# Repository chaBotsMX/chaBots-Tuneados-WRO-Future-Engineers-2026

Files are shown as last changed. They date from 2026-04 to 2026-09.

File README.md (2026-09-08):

# ChaBots - WRO Future Engineers 2026

<!--<img src="https://github.com/chaBotsMX/chaBots-NERV-WRO-Future-Engineers-2025/blob/docs-nacional/v-photos/resources/ChaBotsLogo.png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" width="250">-->

## Follow us!

<!-- Facebook -->

<a  href="https://www.facebook.com/chabotsMX/">

Facebook

</a>

<!-- Instagram -->

<a  href="https://www.instagram.com/chabotsmx/"  target="_blank">

Instagram

</a>

<!-- YouTube -->

<a  href="https://www.youtube.com/@chabotsmx1956/videos"  target="_blank">

YouTube

</a>

This repository contains the documentation for **ChaBots'** participation in the **WRO Future Engineers 2026** category. Our robot was designed and built by a team of Mexican students passionate about robotics and education.

## Competition Videos 

Watch Pistonudo complete the Open and Obstacles challenges. Select a preview to open the corresponding video on YouTube.

| Open Challenge | Obstacles Challenge |
|:---:|:---:|
| Watch the Open Challenge (https://youtu.be/oslJ-CmbmxM) | Watch the Obstacles Challenge (https://youtu.be/23dmH0szIEk) |
| [▶ Watch Open Challenge](https://youtu.be/oslJ-CmbmxM) | [▶ Watch Obstacles Challenge](https://youtu.be/23dmH0szIEk) |

## 📜 Table of Contents

🎬 [Competition Videos](#competition-videos)

1. 🧑‍💻 [The Team](#the-team)
2. 🎯 [The Challenge](#the-challenge)
3. 🏆 [Lessons from the Previous Season](#experience-from-last-year)
4. 🔬 [Research, Development and Decision Log](#rd)
5. 🤖 [Final Robot Architecture](#robot-overview)
6. ⚙️ [Mobility Management](#mobility-management)
7. 💡 [Power, Electronics and Sensor Management](#electronics)
8. 💻 [Software Architecture and Control](#software-architecture)
9. 🚧 [Obstacle Management](#obstacle-management)
10. 🧪 [Testing, Validation and Results](#testing-validation)
11. 🛠️ [Construction, Serviceability and Debugging](#construction-guide)
12. 💰 [Cost Report](#cost-report)
13. 📚 [Resources](#resources)
14. 📋 [Engineering Development Log](#engineering-log)
15. ©️ [License](#license)
---

## 1. The Team 

<div  align="center">

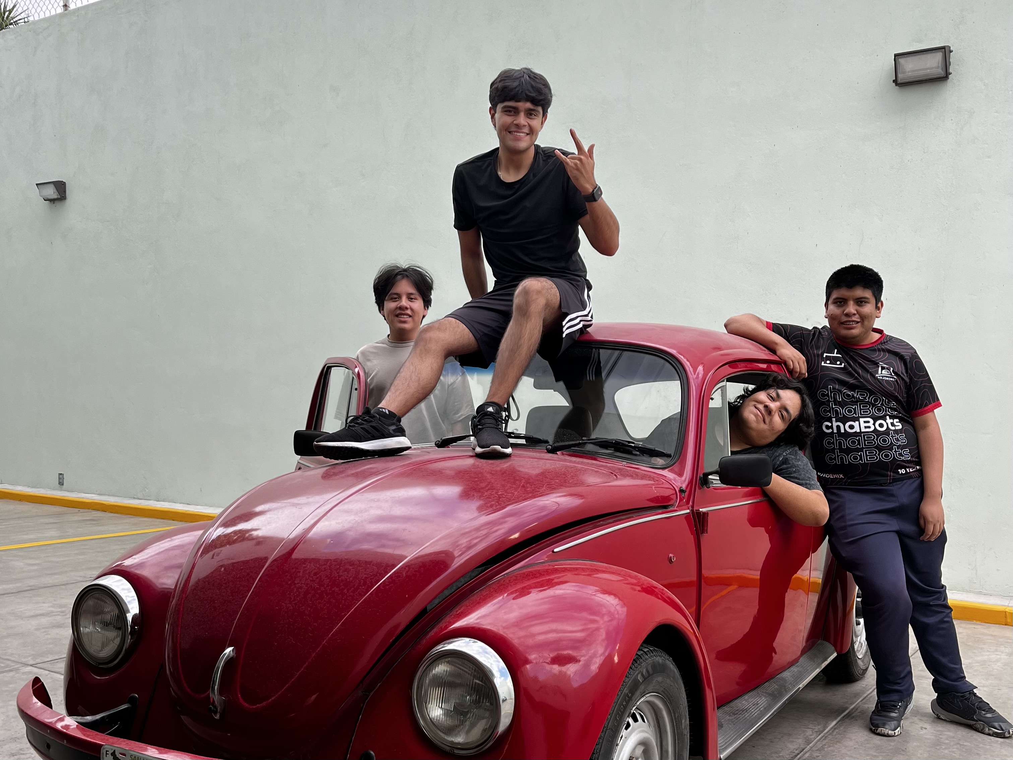
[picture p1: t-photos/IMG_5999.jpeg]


</div>

<div  align="center">

<h2  style="color:#1e90ff; font-size:2.2em; margin-top:0.5em; margin-bottom:0.2em;">

<span  style="color:#222; background:linear-gradient(90deg,#1e90ff,#00c3ff,#00ffb3,#1e90ff);-webkit-background-clip:text;-webkit-text-fill-color:transparent;">We are <b>ChaBots Tuneados</b></span> -[:]

</h2>

</div>

### Roy Iván Barrón Martínez

**Age:** 21

**Role:** Captain & Software Designer

I am a self-taught robotics enthusiast with experience in embedded systems, software, and mechanical integration. my team ChaBots Ocelot won Mexico Robocup soccer Open second place and achieved multiple national awards in programming and robotics.

> "I enjoy setting nearly impossible goals to push myself while learning. I believe that learning should always lead to building something real."

---

### Leonardo Villegas López

**Age:** 21

**Role:** Mechanical Designer

I am a Mechatronics Engineering student passionate about technology and innovation. I have been a contestant for eight years, winning various regional and national competitions, and participating internationally.

> "I will take any opportunity to grow"

---

### Hugo Iván Guerrero Díaz

**Age:** 19

**Role:** Electronics Designer

I am a Mechanical Engineering student that has been participating in robotics competitions since 2019. I won at the RoboCup Mexican Open and represented Mexico at the international RoboCup event in Brazil.

> "I miss her."

---

### Diego Vitales Medellín

**Age:** 23

**Role:** Coach

I've been involved in robotics for more than 14 years, working as a programmer on most of the projects in which I have participated. I have had many regional, national, and international experiences. I now share that knowledge to help others develop their skills, reach their goals, and find their passion.

> "I like to face challenges and even more so when it's with more people. Learning and creating something is better when shared."

---

## 2. The Challenge 

The **WRO Future Engineers** challenge pushes students to create fully autonomous self-driving vehicles. Each robot must:

- Navigate a dynamically randomized track

- Detect and avoid colored obstacles (green/red blocks)

- Execute a parallel parking maneuver

Scoring is based on:

- Performance on track

- Obstacle handling

- Documentation quality

- Innovation and engineering rigor

For more information, visit the [WRO official website](https://wro-association.org/).

---

## 3. Lessons from the Previous Season 

### 3.1 What Happened

Last year was an incredible experience. We were able to achieve first place nationally and later reached 36th place at the international competition. Beyond the results, we identified several important issues in our robot. We also took notes on what we observed and discussed with other teams, which gave us valuable information to improve almost every aspect of our design.

### 3.2 Design Philosophy

Our design philosophy has not changed much from last year. Instead, we found better ways to accomplish what we had originally planned.

Historically, in this and other competitions, we have preferred to build a new robot from scratch every year. We believe this is one of the best ways to push ourselves to improve, learn from previous mistakes, and avoid repeating old limitations. Because of that, this remains one of our core design principles.

Our main design goals are:

- Small size

- Reliability

- Avoiding unnecessary overengineering

- Consistency

### 3.3 What Went Wrong

Our robot had three main issues, which affected us mostly during the obstacle round:

- Poor steering design

- Poor camera software and camera ecosystem

- Poor low-speed movement control

Our steering design was good enough for the open round. In fact, we were able to complete some runs in only 22 seconds. However, it performed very poorly in the obstacle round because the robot was not able to take tight turns. This was mainly caused by the mechanical design of the steering system. We will explain this in more detail later.

The camera software itself was not necessarily terrible, but the entire camera ecosystem was problematic. Last year, we decided to use ROS2, which turned out to be a bad choice for our specific needs. Using ROS2 usually means working with Ubuntu or another Linux distribution instead of simply using Raspberry Pi OS. Although ROS2 can be used on Raspberry Pi OS, it is generally easier to use it with Ubuntu.

This decision caused several problems. Our camera required unusual drivers that were not official and had almost no documentation. As a result, we had trouble disabling white balance and automatic brightness. We also experienced significant camera delay, processing delay, and inconsistent image behavior.

The movement system was good, but it was not optimal for the obstacle round. We needed precision, but our motors were focused more on speed. Since our motors did not have encoders, we could not control low-speed movement accurately. Even though the motors had good torque, it was not enough to move smoothly at low speeds. This was one of the reasons why we were unable to leave the parking lot last year.

## 4. Research, Development and Decision Log 

This year, we spent a lot of time on research and development to solve the issues mentioned above and improve our overall performance.

This section will be quite large because we want to include everything we found important and useful, not only for us, but also for other teams.

We decided to go back to the basics and review everything we might have missed last year.

### 4.1 Mobility

The first thing that comes to mind when talking about mobility is motors. Motors are one of the most important parts of any robot. However, we found that even a good motor is not enough without a good steering system.

Still, let us start by talking about the motors.

#### 4.1.1 Which Motor Should We Use?

First, we need to understand what makes one motor different from another.

The most important characteristics are:

- Speed, measured in RPM

- Torque, usually measured in kg·cm or N·m

- Current consumption, measured in amps

- Weight, measured in grams

- Price

The first thing most people consider when choosing a motor is speed. However, speed cannot be analyzed alone. In electric motors, speed is directly related to torque. In general, the more torque a motor has, the less speed it will have. Likewise, the more speed it has, the less torque it will provide.

This relationship is known as the torque-speed curve, and it is present in every motor. If we want more torque, we usually have to sacrifice speed.

The only way to reduce this limitation is to buy a better motor or use a more powerful one. However, using a more powerful motor usually means higher current consumption.

The following table compares some motors we considered. We usually prefer motors from known brands because generic motors often have poor quality and unrealistic specifications.

| Model | Speed (RPM) | Torque (kg/cm) | Current (A) | Weight (g) |Voltage| Price (USD) |
|---|---|---|---|---|---|---|
| Maxon DCX19 | 600 | 6.5 | 2.0 | 80 |12V| 500 |
| Pololu 25D HP 20.4:1 | 480 | 4.8 | 6.0 | 107 | 6V|37.95 |
| Pololu 25D LP 9.7:1 | 630 | 1.3 | 2.0 | 100 | 6V|33.00 |
| Generic (Pololu 25D copy) | 620 | 0.22 | not specified | 120 |12V|10.00 |
| Lego EV3 (EV3 Medium Motor, 45503) | 240-260 (no-load) |~2.2 kg·cm stalled| no-load ~0.10 A, stall ~0.62 A | 42 g | ~9V (powered by EV3) | low ($) |
| Pololu 25D HP 20.4:1 (with encoder)| 500 | 7 kg·cm stalled| no-load 0.30 A, stall 5.00 A | 120 g | 12V  | 56.95 |

Before choosing a motor, we need to understand what we need from it. In this case, a robot built for Future Engineers must weigh a maximum of 1.5 kg. Torque is not only important for making the robot move. It also affects:

- The ability to accelerate quickly

- The ability to climb small inclines

- The ability to overcome small obstacles

- The ability to maintain speed under load

- The ability to stop quickly

- The ability to reverse quickly and change direction

So, how much torque do we need?

This is a complex question because it depends on many factors, such as the weight of the robot, wheel friction, track surface, and target speed. However, we can use our experience as a starting point.

In our case, we know from experience that we need at least twice the robot’s weight in torque. If our robot weighs 1.5 kg, we need at least 3 kg·cm of torque. This is only a starting point, but it is a useful reference.

Regarding RPM, we know that we do not need extremely high speed because the track is small and the robot must be able to stop quickly. For this reason, we can sacrifice some speed in exchange for more torque. A target speed of around 350 to 400 RPM is usually enough.

However, this target refers to the actual speed at which we want the motor to run, not necessarily the motor’s rated RPM. It is not ideal to run a motor at its maximum rated speed all the time because torque will be lower and current consumption will be higher. Instead, it is better to choose a motor with a higher rated speed and operate it below its maximum.

For example, if we need around 400 RPM, we can choose a motor rated for 500 to 700 RPM. This allows us to run the motor at a lower percentage of its rated speed, which gives us better torque and lower current consumption. As a reference, good-quality motors can usually run at 70% or 80% of their rated RPM without problems. A 600 RPM motor, for example, can be used around 420 RPM reliably.

Now that we know the approximate torque and speed we need, we can talk about power consumption.

Choosing between a 6 V motor and a 12 V motor mainly depends on the battery we plan to use. If we use a 6 V battery, we should choose a 6 V motor. If we use a 12 V battery, we should choose a 12 V motor.

However, in practice, it is not always that simple. LiPo batteries do not provide a constant voltage. For example, a 2S LiPo battery has a nominal voltage of 7.4 V, but it can be fully charged at 8.4 V and drop close to 6 V when it is almost empty.

This is usually not a serious problem because most motors can handle a small amount of overvoltage. Undervoltage is also not dangerous for a DC motor; the motor will simply run slower or may not move if the voltage is too low.

The real issue is that torque and RPM are directly related to voltage. If the battery voltage drops, the robot may lose torque and speed. This is something to consider when diagnosing movement problems. Sometimes the robot may not move correctly simply because the battery is almost empty.

One possible solution is to measure the battery voltage and compensate for it in software to keep the speed more constant. This is not strictly necessary, but it can help a lot.

There are two common types of motors we can use: simple DC motors and DC motors with encoders. In many cases, they are the same motors, but with an encoder added. Encoders are important when precision and control are needed.

Last year, we completed the challenge without encoders, but we found that having full control over motor speed would allow us to implement features that could help in specific situations, such as leaving the parking lot. We are also preparing for possible new mystery rules this year, so having better control gives us more flexibility.

Finally, we need to talk about price. Good-quality motors are expensive, but they are usually worth it because they last longer, perform better, and are more reliable. If you can afford them, it is usually a good investment. However, if you cannot, there are still good options available. Pololu motors, for example, are good enough for many hobby and competition applications.

There are much better motors, such as Maxon motors, which are used in industrial and even aerospace applications. However, for many robotics competitions, Pololu motors offer a good balance between price, quality, and performance.

It is also important to mention that motor requirements can be calculated. There are many online calculators that can help estimate torque and speed requirements. However, the most important thing is to test the motor under real conditions because theoretical calculations are not always accurate.

After considering all of this, we chose the **Pololu 25D Metal Gearmotor 20.4:1 HP 12 V with 48 CPR Encoder, product #3203**. Its documented no-load output speed is approximately **500 RPM** at 12 V. This exact designation is used throughout the current-robot sections of this README.

Last year, we used the Maxon DCX19, and it worked very well for speed. We were able to complete the open round in less than 20 seconds. Our fastest run was 18 seconds. Even in the tightest case, where all four inner walls were present and there was only around 40 cm of space for the robot to drive, we were able to complete the round in 35 seconds.

However, we had many issues in the obstacle round because we did not have good control at low speeds. This is the main reason why we chose motors with encoders this year instead of using the Maxon motors again.

The Maxon motors are linear, smooth, and easy to predict. However, with encoders, we can achieve accurate movement through feedback control instead of relying only on the quality and natural behavior of the motor. This also gives us the possibility to move at lower speeds with much better accuracy.

#### 4.1.2 Which Motor Should We Use? Servo Edition 

Why to use a servo?

We need a simple and reliable steering system, and a servo is perfect for this. We do not need extremely high speed or extreme torque. We only need to turn the wheels accurately and consistently.

Most teams already know this, but we want to share our experience. This section will be shorter because choosing a servo is not as complex as choosing a drive motor.

Here are some servo options:

| Model | Torque (kg/cm)| Current (A) | Size|Weight (g) |Quality| Price (USD) |
|---|---|---|-----|---|---|---|
| HS 85MG | 3 | 1.2 | Small| 21 |Excellent| 40.00 |
| MG996 |  13 | 1.2 | Really big| 66 | Bad|10.00 |
| MG95 |  1.8 | 1.0 | Small| 9 | Bad|2.00 |

This is only a comparison between the servo we chose and some generic options. There are many good servo brands, but comparing all of them would make this section too long.

We chose the HS-85MG because it is a high-quality servo with metal gears, good torque, and a compact size.

The most important factor when choosing a servo is torque. The servo must have enough torque to turn the wheels. If there is too much weight over the steering system, the servo may struggle to move the wheels. Because of this, we need a servo with enough torque for the mechanical load.

It is easy to find servos with a lot of torque, but they are usually large. This may not be a problem for every team, but it is a problem for us because we want to keep the robot as low as possible. That is why we chose this servo: it is small, has good torque, and works reliably.

The HS-85MG provides around 3.0 kg·cm of torque at 5 V. It is expensive, but in our case, it was worth it. If you need a more affordable option, you can use a generic servo, but make sure to test it carefully before using it in a real competition robot.

#### 4.1.3 What Makes a Servo Good Quality?

It is easier to understand servo quality by looking at the problems that low-quality servos can have. The first issue is that the specifications are often inaccurate or exaggerated. However, that is only the beginning.

Bad-quality servos can have problems such as:

- Poor control

- Imprecise movement

- High backlash

- Short lifespan

- Inconsistent behavior under load

Servos are usually easier to choose than drive motors. Good servos are common, and even some generic servos can work well. However, there are also many low-quality clones, so it is important to test them before using them in an important project.

### 4.2 Integrating Both Motors into a Steering System 

After selecting the drive motor and steering servo, the next step was to integrate them into one mechanically consistent mobility system. This was one of the most important design decisions because motor performance alone does not determine how accurately the robot moves. The geometry, transmission, wheel alignment, structural stiffness, tire behavior, and weight distribution all affect the final trajectory.

#### Regulatory constraints

The 2026 Future Engineers rules require a four-wheeled vehicle with **one driving axle and one steering actuator**. Front-wheel drive, rear-wheel drive, and four-wheel drive are permitted, but a differential-wheeled robot and an electronic differential with independently driven left and right sides are not allowed.

The rules also permit a maximum of two driving motors, but they must be mechanically connected to the driving axle and cannot independently control the left and right wheels. Therefore, our drivetrain had to behave as one mechanically coupled drive system rather than steering by changing the speed of each side.

This requirement creates a different design problem from a differential-drive robot. Direction changes must be produced by steering geometry, while the coupled driving wheels continue receiving the same mechanical input.

#### Designing a competition robot rather than a scaled car

Last year, we approached the vehicle as if we were building a small conventional car. This provided a useful starting point, but this year we recognized that the objective is not to reproduce a road vehicle visually. The objective is to engineer the most effective robot for the dimensions, speeds, materials, rules, and field conditions of this challenge.

Full-size automotive principles such as Ackermann steering, controlled weight distribution, rigid wheel alignment, and low mechanical play remain useful. However, their implementation must be adapted to a lightweight robot made with small servos, printed components, compact bearings, and tires that deform differently from full-size vehicle tires.

For this reason, the new robot does not attempt to look like a Formula 1 car or reproduce a real vehicle at scale. Its geometry was designed around the competition task, available manufacturing methods, required turning radius, sensor placement, and serviceability.

#### Main mechanical challenges

| Problem | Principal causes | Effect on the robot | Design response |
|---|---|---|---|
| Backlash and compliance | Clearance between gear teeth, servo gearbox play, loose joints, output-spline movement, flexible printed parts, and bearing clearance | Delayed steering response, oscillation, inconsistent straight-line position, and different behavior when changing direction | Better servo, rigid supports, short linkages, controlled gear center distance, reduced joint clearance, and calibration from both steering directions |
| Front-wheel scrub | Both front wheels using the same steering angle instead of following their individual turning circles | Tires fight each other, steering load increases, speed decreases, and the robot follows a larger or inconsistent turn | Ackermann steering geometry with a greater angle on the inside wheel |
| Driven-axle scrub | Mechanically coupled left and right drive wheels rotate together even though the outside wheel travels farther during a turn | One or both rear tires must slip, especially during tight or high-speed turns | Appropriate wheelbase and track width, compliant tires, controlled cornering speed, good alignment, and predictable weight distribution |
| Loss of tire contact | Twisted chassis, unequal wheel height, poor assembly tolerances, or an unsuitable center of mass | Encoder distance no longer matches robot movement and the vehicle can pull toward one side | Rigid chassis, coplanar axle installation, low center of mass, and verification that all four wheels remain loaded |
| Insufficient steering range | Linkage collision, limited servo travel, unsuitable servo-horn length, or wheel interference with the chassis | Large minimum turning radius and difficulty leaving or entering the parking area | CAD interference checks, mechanical steering stops, optimized linkage leverage, and maximum safe inner-wheel angle |
| Excessive grip or insufficient grip | Tire compound, surface material, axle load, and speed | Too little grip causes uncontrolled sliding; excessive lateral grip increases scrub in the coupled axle | Tire testing on the competition surface and speed-dependent steering control |

#### Backlash

**Backlash** is the lost motion that appears when the direction of a mechanism reverses before the output begins moving. In our robot it can originate in several places:

- Clearance between the transmission gear teeth.
- Internal play in the servo gearbox.
- Clearance between the servo spline and horn.
- Loose steering-link joints or fasteners.
- Flexible printed brackets and shafts.
- Bearing or axle play.

Backlash is not caused by the gear teeth returning to a relaxed position. It is mainly produced by clearance and elastic deformation within the transmission. Increasing the number of teeth does not automatically solve it.

Our drivetrain uses double-helical, or herringbone-style, gears. Their gradual tooth engagement and higher contact ratio can produce smoother transmission, while the opposing helix directions balance axial forces. However, this geometry does not eliminate backlash by itself. Tooth profile, printing accuracy, shaft alignment, bearing support, and gear center distance still determine the remaining play.

The steering actuator can introduce even more lost motion than the printed transmission. This was one reason for choosing the higher-quality HS-85MG servo discussed in [Section 4.1.2](#servo-selection). We also reduced linkage length and unnecessary joints so that servo movement reaches the wheels with less deformation.

#### Tire slip and Ackermann geometry

During a turn, every wheel follows a circle with a different radius around one instantaneous center of rotation. The inside front wheel must therefore turn farther than the outside front wheel. If both front wheels remain parallel, at least one tire must slide laterally.

Ackermann steering approximates the required relationship by arranging the steering arms and tie rods so that the projected wheel axes intersect near the rear axle. For wheelbase (L), front track width (T), and turn radius (R) measured to the vehicle centerline:

```math
\tan(\delta_{inside}) = \frac{L}{R - T/2}
```

```math
\tan(\delta_{outside}) = \frac{L}{R + T/2}
```

Therefore, the inside steering angle must always be greater than the outside angle.

Ackermann geometry reduces front-wheel scrub, but it cannot completely eliminate slip in our driven axle. Because the two driving wheels are mechanically coupled, they tend to rotate through the same angle even though the outside wheel must travel farther. This is an unavoidable compromise of a locked or non-differential axle. Our objective was therefore to make the remaining slip controlled and repeatable rather than assume it could be removed completely.

The factors we used to reduce unpredictable slip were:

- Correct inner- and outer-wheel steering angles.
- Accurate toe alignment when the servo is centered.
- A rigid but accurately assembled chassis.
- Tires with sufficient forward grip and moderate lateral compliance.
- A low center of mass with enough load on both the steering and driving axles.
- Four wheels making consistent contact with the surface.
- Reduced speed before tight turns.
- Encoder and IMU feedback to detect when actual movement differs from the commanded movement.

#### Turning radius

The geometric turning radius depends mainly on wheelbase and steering angle. A simplified bicycle model gives:

```math
R \approx \frac{L}{\tan(\delta)}
```

A shorter wheelbase or a greater steering angle reduces the theoretical radius. In practice, however, simply commanding a greater angle does not guarantee a tighter turn. Tire scrub, servo backlash, linkage deformation, insufficient torque, and wheel-to-chassis interference can make the real turning radius larger than the calculated value.

The servo linkage also creates a tradeoff between steering range, torque, and resolution. A long servo horn can provide more wheel travel but reduces mechanical advantage and makes each servo step produce a larger wheel-angle change. A shorter horn improves force and angular resolution but may not provide enough steering range. We selected the horn length and steering-arm geometry through CAD interference checks and physical testing.

#### Final mechanical integration

The final system combines:

- A **Pololu 25D Metal Gearmotor 20.4:1 HP 12 V with 48 CPR Encoder (#3203)** for propulsion and wheel-motion feedback.
- A mechanically coupled driving axle, compliant with the non-differential-drive requirement.
- A double-helical printed transmission for compact and smooth power transfer.
- One **HS-85MG servo** controlling both steering wheels.
- Ackermann-oriented steering arms so that the inside wheel turns farther than the outside wheel.
- Mechanical steering limits to prevent the servo from forcing the linkage beyond its safe range.
- Encoder and BNO085 feedback to compare commanded movement with actual displacement and heading.
- ToF wall measurements to correct accumulated movement errors.

The mechanical design and software controller were developed together. The steering geometry reduces predictable tire scrub, while the encoder, IMU, and ToF fusion compensate for errors that cannot be eliminated mechanically.

One iteration directly changed the final mechanism. Early track tests showed that the front tires scrubbed and the vehicle followed a wider path than commanded. The team recalculated the steering geometry from the real wheelbase and track width, implemented Ackermann-oriented steering arms, and shifted load toward the front axle. The resulting path was visibly smoother and no longer showed the original obvious overshoot; the remaining quantitative checks are listed in the verification procedure below and the complete problem-change-result record is preserved in [ERR-MEC-001](#err-mec-001--front-wheel-slip-reduced-steering-authority).

#### Verification procedure

To validate the assembly, we use the following checks:

1. Center the servo electronically and verify that both front wheels have the intended neutral toe.
2. Move the steering slowly in both directions and measure the dead band caused by backlash.
3. Measure the inside and outside wheel angles at several servo commands.
4. Verify that no steering link, wheel, or servo horn collides with the chassis.
5. Confirm that all four wheels remain in contact with a flat surface.
6. Measure the minimum left and right turning radii at low speed.
7. Repeat the radius test at higher speed and observe tire scrub or trajectory changes.
8. Compare encoder-estimated travel with measured vehicle displacement.
9. Repeat the tests after disassembly and reassembly to evaluate mechanical repeatability.

These measurements allow the geometry and controller values to be based on evidence rather than visual judgment alone.

**Technical reference:**

- [WRO 2026 Future Engineers General Rules, Sections 11.3, 11.5, and 11.13](https://wro-association.org/wp-content/uploads/WRO-2026-Future-Engineers-Self-Driving-Cars-General-Rules.pdf)

### 4.3 Sensor Changes 

#### 4.3.1 Sensor Candidates

One of the most significant changes in this iteration was the sensing architecture. None of the sensors from the previous version were reused without first evaluating alternative technologies.

The candidates were grouped according to their intended function:

| Category | Candidate sensors | Intended purpose |
|---|---|---|
| Distance sensing | HC-SR04, URM09, VL6180X, VL53L0X, VL53L1X, VL53L8CX, and RPLIDAR C1 | Wall detection, obstacle detection, and distance control |
| Position and odometry | SparkFun OTOS and Pololu 25D wheel encoders | Estimation of displacement, orientation, and vehicle position |
| Reference and color detection | Photoresistors, TCS-series sensors, and ALS-PT19 | Detection of lighting, colors, and visual track references |
| Visual perception | Raspberry Pi Camera Module 3, OpenMV Cam H7, and OpenMV N6 | Object classification, color recognition, and image-based navigation |

The candidates were compared according to cost, measurement range, field of view, update rate, power consumption, communication interface, environmental resistance, and expected reliability on the competition field. Price was not treated as the only selection criterion: a low-cost sensor can have a long advertised range while still producing unstable measurements on angled surfaces, dark objects, or under strong ambient light.

#### 4.3.2 Distance Sensing 

We evaluated ultrasonic sensors, single-zone ToF sensors, a multizone ToF sensor, and a rotating 2D LiDAR. The comparison considered not only maximum advertised range, but also update rate, field of view, ambient-light resistance, target reflectivity, power consumption, cost, and behavior while the robot was moving.

The reliability ratings below describe suitability for our moving WRO vehicle and are based on both datasheet information and our own tests. They are not general ratings of the manufacturing quality of each sensing technology.

| Sensor | Approx. price | Measurement type | Interface | Maximum update rate | Nominal range | Supply and consumption | Reliability and observed behavior |
|---|---:|---|---|---:|---:|---|---|
| HC-SR04 | US$1–3 | Single-direction ultrasonic | Trigger/Echo GPIO | Approximately 16 Hz recommended | 2–400 cm | 5 V, approximately 15 mA | **Low.** Results varied considerably between manufacturers, and the origin and quality of generic modules were difficult to verify. Measurements were especially inconsistent while the robot was moving. |
| DFRobot URM09 | US$12–20 | Single-direction ultrasonic | I2C | Up to 50 Hz | 2–500 cm | 3.3–5.5 V, approximately 20 mA | **Medium.** It produced usable measurements at approximately 150 cm while the vehicle was moving quickly. However, its wide 60° field of view caused it to detect adjacent walls in narrow sections of the field. |
| VL6180X | US$1.50–4 | Single-zone ToF | I2C | 10 Hz in the reference low-power configuration | 0–10 cm | Generic modules usually accept 3.3–5 V; approximately 1.7 mA average at 10 Hz | **High only at very short distances.** Its limited range made it unsuitable for the main wall-distance system. |
| VL53L0X | US$2.50–5 | Single-zone ToF | I2C | Approximately 30 Hz with a 33 ms timing budget | Up to 200 cm | Generic modules usually accept 3.3–5 V; approximately 19 mA while ranging | **Medium.** In our tests, its performance against dark surfaces and ambient light was similar to or worse than that of the VL53L8CX. It also returned only one distance value per sensor. |
| VL53L1X | US$4.50–8 | Single-zone ToF with adjustable region of interest | I2C | Up to 50 Hz | Up to 400 cm | Generic modules usually accept 3.3–5 V; approximately 16 mA while ranging | **Medium to high.** Its advertised range was greater than required, but in most of our tests it did not provide a significant reliability advantage over the VL53L8CX. |
| VL53L8CX | US$20–30 | 4×4 or 8×8 multizone ToF depth sensor | I2C or SPI | Up to 60 Hz at 4×4; up to 15 Hz at 8×8 | 2–400 cm per zone | Carrier-board dependent; approximately 215 mW in continuous mode | **High for our use case.** Black walls were normally detected from approximately 80–100 cm, which was sufficient for control. It was the most resistant ToF sensor to changing ambient-light conditions and provided multiple distance zones in every frame. |
| RPLIDAR C1 | US$80–100 | 360° rotating 2D direct ToF LiDAR | TTL UART at 460800 baud | 8–12 complete scans/s specified; approximately 5 complete scans/s observed in our system | 5–1200 cm on white targets and approximately 5–600 cm on black targets | 5 V, approximately 230 mA while operating and up to 800 mA during startup | **High spatial accuracy, but low temporal suitability at our vehicle speed.** Its approximately 5 Hz effective scan rate caused the map to become outdated while the robot was moving quickly. |

##### Why we selected the VL53L8CX

Our tests showed that the **VL53L8CX was the most appropriate sensor for the new vehicle**. It did not reliably detect the competition's black wall beyond 1 m, and under some conditions its maximum useful range was approximately 80 cm. This was sufficient because our controller did not require a complete long-range map of the field.

The main reason for selecting it was its resistance to changing ambient-light conditions. The lighting at the competition venue cannot be predicted, so robustness under different ambient-light levels was more important to us than maximum theoretical range. The single-zone VL53 sensors performed similarly or worse in most of our tests.

The VL53L8CX also returns a depth grid instead of one distance. This allows the software to compare neighboring zones, reject invalid readings, and obtain information about the position of a nearby wall without depending on a single measurement. Four compact sensors can be positioned around the robot to observe only the directions required by the controller.

##### Why we did not retain the RPLIDAR C1

The RPLIDAR C1 could detect the black wall at approximately 6 m and generally produced more precise long-range measurements. However, that range was not necessary for our control strategy.

The LiDAR generates approximately 5,000 individual distance samples per second, but these samples are distributed over a complete 360° rotation. This must not be confused with the rate at which the controller receives a complete scan. Although the manufacturer specifies 8–12 rotations per second, our complete acquisition and processing pipeline normally produced approximately **5 usable scans per second**.

At high vehicle speeds, the robot changed position significantly between complete LiDAR scans. Sensor fusion reduced this problem but could not remove the latency already present in the measurements. For our application, a shorter sensing range with more useful local information was preferable to a long-range 360° map that was updated too slowly.

##### Sensor fusion with wheel encoders

The new robot combines the quadrature encoder integrated into the **Pololu #3203 25D gearmotor** with the VL53L8CX measurements. The encoder provides high-frequency relative motion information between ToF frames, while the ToF sensors provide external references to nearby walls.

Consequently, the ToF sensors do not need to observe the entire field continuously. Encoder odometry estimates the robot's movement when no suitable wall is visible, and valid ToF measurements are used to correct accumulated position and orientation error when a wall enters the useful measurement range.

This architecture provided a better balance between environmental robustness, useful update rate, short-range wall detection, processing requirements, power consumption, cost, and mechanical simplicity.

**Technical references:**

- [HC-SR04 datasheet](https://www.digikey.com/en/htmldatasheets/production/3822706/0/0/1/hc-sr04.html)
- [DFRobot URM09 specifications](https://wiki.dfrobot.com/sen0304/)
- [STMicroelectronics VL6180X datasheet](https://www.st.com/en/datasheet/vl6180x.pdf)
- [STMicroelectronics VL53L0X datasheet](https://www.st.com/resource/en/datasheet/vl53l0x.pdf)
- [STMicroelectronics VL53L1X datasheet](https://www.st.com/resource/en/datasheet/vl53l1x.pdf)
- [STMicroelectronics VL53L8CX datasheet](https://www.st.com/resource/en/datasheet/vl53l8cx.pdf)
- [SLAMTEC RPLIDAR C1 specifications](https://www.slamtec.com/en/c1/spec)

#### 4.3.3 Position and Movement 

Last year, we used a **SparkFun Optical Tracking Odometry Sensor (OTOS)**. The OTOS combines an optical tracking sensor, a six-axis IMU, and an onboard microcontroller that performs sensor fusion. It directly provides planar position (x and y) and heading, so it can perform part of the work normally divided between wheel encoders and an IMU.

It was good enough for the previous robot, but our tests showed consistency and reliability problems at low speeds. Its optical measurement also depended on its mounting height and on the texture, color, and illumination of the floor. Because the competition venue can have environmental conditions that differ from our workshop, we decided to replace this single-source position estimate with separate sensors whose information could be fused and independently verified.

##### What an IMU measures

An **Inertial Measurement Unit (IMU)** does not directly measure the robot's global position. A typical six-axis IMU contains:

- A three-axis **gyroscope**, which measures angular velocity. Integrating this velocity provides changes in yaw, pitch, and roll, but small bias errors accumulate into drift.
- A three-axis **accelerometer**, which measures specific force, including gravity. Gravity can help stabilize pitch and roll, but an accelerometer cannot provide an absolute yaw reference.

A nine-axis orientation system also includes a three-axis **magnetometer**. The magnetometer measures Earth's magnetic field and can provide an absolute heading reference, but its readings are easily disturbed by motors, high-current wiring, magnets, steel fasteners, and the magnetic characteristics of the venue.

An IMU does not necessarily perform sensor fusion by itself. Low-cost modules often provide only raw accelerometer, gyroscope, and magnetometer readings. Devices such as the **BNO055** and **BNO085** include an internal processor that combines these measurements and provides orientation outputs such as rotation vectors, yaw, pitch, and roll.

##### Drift and environmental interference

Drift is not one single error and it cannot be completely removed simply by purchasing a more expensive sensor:

- **Gyroscope bias** accumulates when angular velocity is integrated over time.
- **Magnetometer interference** changes the apparent direction of magnetic north.
- **Wheel encoders** measure wheel rotation, but their position estimate accumulates error when the wheels slip.
- **Optical odometry** depends on the floor texture, sensor height, illumination, and whether the surface provides enough visible detail.
- **Accelerometer integration** amplifies small noise and bias errors, making it unsuitable as the only long-term position estimate.

A robot can therefore work correctly at our school and behave differently at the competition venue. The magnetic field, lighting, floor material, mechanical vibration, and nearby electrical equipment can all affect its sensors.

The main methods we considered for reducing these errors were:

1. **Mechanical and electrical placement:** keeping the IMU away from motors, magnets, high-current wires, and switching power components.
2. **Gyroscope calibration:** estimating the stationary zero-rate bias before the robot begins moving.
3. **Hard-iron calibration:** removing a constant magnetometer offset caused by permanent magnetic fields on the robot.
4. **Soft-iron calibration:** compensating for the scaling and distortion produced by nearby ferromagnetic materials.
5. **Sensor-fusion filters:** using complementary, Kalman, or manufacturer-provided fusion algorithms to combine measurements according to their strengths.
6. **External corrections:** using wall measurements, visual references, or a map to correct the accumulated error of relative sensors.

More expensive fused IMUs reduce the amount of filtering software that the team must develop, but they still require correct mounting, calibration, configuration, and testing in the completed robot.

##### Position and orientation comparison

The **GY** prefix does not identify a specific sensor or manufacturer. It is commonly used for generic breakout-board designs, and two boards with the same printed name can contain different or substituted integrated circuits. For this reason, the exact chip marking, I2C identification register, schematic, regulator, and logic-voltage compatibility must be verified before comparing or using one of these modules.

| Device | Measurement principle | Approx. price | Interface and output | Update capability | Reliability in our application | Main limitation |
|---|---|---:|---|---|---|---|
| SparkFun OTOS | Optical floor tracking plus six-axis IMU and onboard fusion | US$84.95 | I2C; x, y, heading, velocity, and acceleration | Optical sensor operates internally at up to 20,000 frames/s | **Medium.** It worked better during faster movement, but our low-speed results were inconsistent. | Depends strongly on floor characteristics, mounting distance, calibration, and illumination. |
| GY-521 / MPU-6050 | Generic six-axis accelerometer and gyroscope module | US$1–6 | I2C; mainly raw acceleration, angular velocity, and temperature | Gyroscope sampling up to 8 kHz; practical fused output depends on the host processor and filter | **Low to medium.** Acceptable for experiments after calibration, but module quality and offsets vary considerably. | No magnetometer or dependable ready-to-use heading; requires host-side calibration and sensor fusion. |
| GY-85 | Generic multi-chip nine-axis module, commonly using ADXL345, ITG3205, and HMC5883L-compatible devices | US$4–9 | I2C; separate raw accelerometer, gyroscope, and magnetometer readings | No unified fused rate; practical fusion commonly runs at approximately 50–200 Hz | **Low to medium.** It can work after extensive calibration, but consistency between sellers is difficult to guarantee. | Old multi-chip design; replacement magnetometers and clone components are common, and all fusion must be implemented by the host. |
| GY-91 / GY-9250 | Generic nine-axis MPU-9250-class IMU, often combined with a BMP280 barometer | US$5–12 | I2C or SPI; raw acceleration, angular velocity, magnetic field, and pressure | High-rate gyro/accelerometer data; magnetometer updates up to approximately 100 Hz | **Medium only after verification and calibration.** A genuine device can produce good results with a well-designed filter. | Advertised MPU-9250 boards may contain substituted MPU-6500 or other chips; no trustworthy plug-and-play fused orientation. |
| BNO055 | Nine-axis IMU with onboard BSX3.0 fusion | US$30–35 | I2C or UART; fused Euler angles, quaternion, and raw sensor data | Fused orientation up to approximately 100 Hz | **Good.** Easier to integrate than a raw low-cost IMU, but less robust than the BNO085 in our tests. | Older device, sensitive to magnetic interference, and Bosch does not recommend it for new designs. |
| BNO085 | Nine-axis IMU with SH-2 onboard sensor fusion | US$25–35 | I2C, SPI, or UART; multiple rotation-vector and calibrated sensor reports | Common fused reports at 100–400 Hz, depending on configuration | **High.** It provided the most stable orientation output of the evaluated IMUs and reduced the fusion work required on the Teensy. | Magnetometer-assisted outputs can still be disturbed by motors and the venue's magnetic field. |
| Pololu 25D quadrature encoder | Incremental wheel rotation | Included with the US$56.95 gearmotor | Two digital quadrature channels; ticks, direction, speed, and relative distance | Pulse rate increases directly with wheel speed | **High for wheel rotation and speed control.** It remains usable at speeds where the OTOS was inconsistent. | Cannot detect wheel slip and accumulates position error without an external reference. |

##### Final position-estimation architecture

We selected the **BNO085 and the integrated Pololu 25D motor encoder** instead of relying on the OTOS as a single position source:

- The **encoder** provides high-rate wheel displacement and velocity feedback, including during low-speed maneuvers.
- The **BNO085** provides heading and angular-motion information with onboard sensor fusion.
- The **VL53L8CX sensors** provide external wall references that can correct accumulated relative-position errors.

This architecture deliberately uses complementary sensors. The encoder remains reliable when no wall is visible, the IMU tracks changes in orientation, and the ToF sensors correct the estimate whenever a valid wall measurement becomes available. A failure or temporary loss of one reference therefore does not immediately remove all movement information from the controller.

**Technical references:**

- [SparkFun OTOS product specifications](https://www.sparkfun.com/sparkfun-optical-tracking-odometry-sensor-paa5160e1-qwiic.html)
- [SparkFun OTOS hardware overview](https://docs.sparkfun.com/SparkFun_Optical_Tracking_Odometry_Sensor/hardware_overview/)
- [TDK InvenSense MPU-6050 product specification](https://invensense.tdk.com/wp-content/uploads/2015/02/MPU-6000-Datasheet1.pdf)
- [TDK InvenSense MPU-9250 register map](https://invensense.tdk.com/wp-content/uploads/2015/02/RM-MPU-9250A-00-v1.6.pdf)
- [Bosch BNO055 product information](https://www.bosch-sensortec.com/products/smart-sensors/bno055/)
- [CEVA BNO08X datasheet](https://www.ceva-ip.com/wp-content/uploads/BNO080_085-Datasheet.pdf)

#### 4.3.4 Cameras

Cameras are optical sensors, but selecting one for a robot involves more than comparing image resolution. The camera, processor, image-transfer interface, available algorithms, exposure controls, frame rate, power consumption, and software environment together determine whether the complete vision system is suitable.

A camera's advertised frame rate is also not necessarily the rate at which the robot receives useful detections. Image capture, color conversion, filtering, inference, and communication all add processing time. For this reason, we compared the rate of the complete detection pipeline rather than considering only the sensor's maximum FPS.

##### Vision-system categories

The evaluated systems can be divided into three practical categories:

1. **Fixed-function smart vision sensors:** Devices such as Pixy2 and HUSKYLENS process images internally and send compact results through UART, I2C, SPI, or USB. They are easy to connect to a microcontroller, but the available algorithms and image controls are more restricted. HUSKYLENS 2 can deploy custom trained models, although its processing pipeline is still less open than a general-purpose programmable camera.
2. **Programmable embedded-vision boards:** OpenMV and MaixCam combine a camera with an MCU or AI SoC. User code runs directly on the board, allowing calibration, regions of interest, color thresholds, filtering, and custom communication protocols without adding a Linux computer.
3. **Camera modules with external processing:** A sensor such as Raspberry Pi Camera Module 3 sends image data to an SBC through a high-bandwidth interface such as MIPI CSI-2. The SBC can run OpenCV or neural-network frameworks and provides the greatest flexibility, but requires more space, power, startup time, and software maintenance.

These categories are independent of whether a product contains an FPGA, MCU, GPU, or NPU. For example, the OpenMV H7 uses an STM32 microcontroller, the OpenMV N6 includes an NPU, and HUSKYLENS 2 uses a Kendryte AI SoC. FPGA-based cameras also exist, but an FPGA is not required for a camera to process images internally.

I2C is generally too slow for transferring complete video frames. On image sensors, it is commonly used to configure exposure, gain, resolution, and other registers. Full images are normally transferred through a parallel camera bus, MIPI CSI-2, USB, or another high-bandwidth connection. Smart cameras can use I2C or UART because they send only small results, such as an object's position and size, rather than the complete image.

##### Camera-system comparison

| Vision system | Architecture | Approx. price | Programmability | Camera or processing rate | Output to main controller | Reliability and main limitation |
|---|---|---:|---|---|---|---|
| ESP32-CAM / OV2640 | Camera sensor with low-cost MCU | US$5–12 | Arduino/C++ or ESP-IDF | Approximately 10–30 useful FPS at reduced resolutions, depending on processing | UART, Wi-Fi, or application-specific protocol | **Low to medium for advanced vision.** Inexpensive and compact, but RAM and processing power limit filtering, resolution, and consistent high-rate detection. |
| Pixy2 | Fixed-function smart camera | US$60–130 | Algorithms are mainly configured rather than freely programmed | Up to 60 processed frames/s | UART, I2C, SPI, USB, digital, or analog | **Medium.** Fast and simple for color signatures and line tracking, but offers limited control over the complete vision pipeline and adaptation to unusual lighting. |
| HUSKYLENS 2 | All-in-one AI vision sensor with Kendryte K230 SoC | US$80–120 | Built-in models and deployment of trained custom models | 2 MP camera at up to 60 FPS; inference rate depends on the selected model | UART, I2C, USB-C, or optional Wi-Fi | **Medium to high.** Much more capable than earlier fixed-function cameras, but it is comparatively large, weighs 90 g, consumes 1.5–3 W, and provides less low-level pipeline control than OpenMV or an SBC. |
| OpenMV Cam H7 | Programmable embedded camera with STM32H743 MCU | US$80 | MicroPython through the OpenMV IDE | Sensor capture up to 75 FPS at VGA and up to 150 FPS below QVGA; algorithm rate depends on the script | UART, I2C, SPI, CAN, or USB | **High for our color-detection task.** Compact, predictable, and fully configurable, but has limited RAM and processing power compared with newer AI boards. This model is no longer in production. |
| OpenMV N6 | Programmable embedded camera with STM32N6 MCU and NPU | US$180–195 | MicroPython, classical vision, and neural-network inference | 1 MP global-shutter sensor up to 120 FPS; YOLO inference at approximately 30 FPS | UART, I2C, SPI, USB-C, Ethernet, Wi-Fi, or Bluetooth | **High for the current robot.** The experimental firmware used by the team provides the white-balance control required by the color-detection pipeline. |
| MaixCam Lite | Programmable embedded AI camera | US$40–70 | MaixPy/Python and deployable AI models | Typically up to approximately 60 FPS, depending on resolution and model | UART, USB, network, or application-specific interface | **Medium in our evaluation.** Good processing capability and size, but the available documentation and development workflow were less mature for our team. |
| Raspberry Pi 5 + Camera Module 3 | Camera sensor with external Linux SBC | US$85–140 combined | Fully programmable with Python/C++, OpenCV, and AI frameworks | Camera supports 1080p50 and high-frame-rate modes at lower resolutions | UART, USB, network, CAN adapter, or other SBC interface | **High when correctly engineered.** Provides the most software flexibility, but consumes substantially more power, occupies more space, takes longer to boot, and increases system complexity. |

##### Environmental reliability

A programmable camera does not automatically solve lighting problems, but it gives the team tools to control them. Important techniques include:

- Locking or limiting automatic exposure after calibration.
- Controlling white balance and sensor gain.
- Defining regions of interest so irrelevant parts of the field are ignored.
- Converting colors into a space that separates chromatic information from brightness.
- Filtering detections by area, aspect ratio, position, and temporal consistency.
- Calibrating thresholds under bright, dark, warm, and cool illumination.
- Rejecting detections that do not persist across multiple frames.

Fixed-function cameras can be reliable when the environment matches their expected conditions. However, if their internal processing cannot be adjusted sufficiently, a lighting change may produce errors that the main controller cannot correct because it never receives the original image.

##### Final decision

Our task only requires detecting red and green obstacles and transmitting a compact description of each valid object to the Teensy. Sending full video to the main controller would add bandwidth and processing requirements without improving the control decision.

The **OpenMV N6** is installed in the current robot. It provides the global-shutter sensor and processing headroom needed for the vision pipeline while keeping the computation onboard. The team uses an experimental firmware that enables the white-balance control required for repeatable color detection.

The N6 program defines color thresholds and regions of interest, locks the relevant automatic image controls during calibration, rejects invalid blobs, and sends only the object's color and image position to the Teensy through UART. The robot does not transmit full video to the navigation controller.

Compared with a Raspberry Pi and Camera Module 3, the N6 starts quickly and keeps the vision stack on a compact embedded board. Compared with Pixy2 or HUSKYLENS, it preserves direct control over calibration and filtering while providing more processing capacity for future work.

**Technical references:**

- [Pixy2 communication and 60 FPS processing](https://docs.pixycam.com/wiki/doku.php?id=wiki:v3:porting_guide)
- [HUSKYLENS 2 specifications](https://wiki.dfrobot.com/sen0638/)
- [OpenMV Cam H7 specifications](https://openmv.io/products/openmv-cam-h7)
- [OpenMV N6 specifications](https://openmv.io/products/openmv-n6)
- [Raspberry Pi Camera Module 3 product brief](https://datasheets.raspberrypi.com/camera/camera-module-3-product-brief.pdf)

### 4.4 Controller and Electrical Architecture Decisions

The final control architecture keeps deterministic vehicle control and ToF acquisition on the Teensy 4.0. The Seeed Studio XIAO ESP32-C6 is retained as a development telemetry bridge, so wireless debugging remains outside the competition-time control loop.

| MCU | Clock speed | Observed PWM behavior | Decision |
|---|---:|---|---|
| Teensy 4.0 | 600 MHz | Excellent; smooth startup and useful torque at low duty cycles | Selected as the main controller |
| Arduino Nano | 16 MHz | Good and predictable | Rejected because of its lower processing and interface capacity |
| Raspberry Pi Pico | 133 MHz | Inconsistent at very low duty cycles in our tested software configuration | Rejected for the main controller |
| Seeed Studio XIAO ESP32-C6 | 120 MHz | Good, with BLE available for development telemetry | Selected as the development telemetry bridge |

These PWM observations are empirical results from our prototypes, not a general ranking of the microcontrollers. Timer configuration, resolution, SDK, and motor-driver implementation can change the result. Wireless telemetry is used only during development and is disabled during official runs.

The electrical design was consolidated into one **8 × 8 cm**, two-layer PCB. A single board reduced interconnects and made the complete system smaller, while a top-mounted layout kept the controllers, power stage, and connectors accessible for repair. The final installed architecture is documented in [Section 7](#electronics).

## 5. Final Robot Architecture 

**Name:** Pistonudo

| Subsystem | Final implementation | Detailed section |
|---|---|---|
| Propulsion | Pololu 25D Metal Gearmotor 20.4:1 HP 12 V with 48 CPR Encoder (#3203), 500 RPM no-load, custom 1:1 double-helical transmission, and rigid rear axle | [Mobility Management](#mobility-management) |
| Steering | HiTEC HS-85MG servo with Ackermann linkage | [Mobility Management](#mobility-management) |
| Wall sensing | Four VL53L8CX multizone ToF sensors read directly by the Teensy 4.0 | [Sensor R&D](#sensor-changes) |
| Position and heading | Pololu encoder, BNO085, and valid wall references | [Position and Movement](#position-and-movement) |
| Obstacle perception | OpenMV N6 color detection | [Obstacle Management](#obstacle-management) |
| Main control | Teensy 4.0 running the navigation state machine and actuator control | [Software Architecture](#software-architecture) |
| Electrical integration | Single 8 × 8 cm PCB with regulated power, motor driver, controllers, and service connectors | [Electronics](#electronics) |

The table is the single overview of the completed robot. The R&D chapter explains **why** each option was selected; the subsystem chapters explain **what** was built; the software chapter explains **how** it operates; and the validation chapter records **what has been measured**.

### 5.1 Competition Version and Release Notes

**Competition documentation version:** `WRO-2026-Competition-v1.0-rc1`

**Firmware baseline:** [`8de5c7b`](https://github.com/chaBotsMX/chaBots-Tuneados-WRO-Future-Engineers-2026/commit/8de5c7bc375f2857ba302f1c0525ff1ad88d9a91)

**Hardware configuration:** Pistonudo with Teensy 4.0, four VL53L8CX sensors, BNO085, OpenMV N6, Pololu #3203 drive motor, and HS-85MG steering servo

**Documentation date:** 2026-09-07

This release candidate establishes one reproducible competition configuration for both Open and Obstacles. It replaces the earlier XIAO-based ToF architecture with direct Teensy SPI acquisition, records the N6 vision contracts, identifies the exact build targets, and defines the remaining field-validation entries. It becomes `v1.0` when the final Open and Obstacles validation rows are completed against this configuration.

The final publication commit should describe the delivered documentation explicitly, for example `document WRO 2026 competition release candidate`; the existing history does not need to be rewritten.

### 5.2 Sensor Placement and Field Geometry

The four distance sensors are mounted orthogonally because each orientation answers a different question created by the rectangular WRO field. The **front** sensor detects an approaching outer wall and provides the distance threshold that begins a corner or blue-line turn. The **left** and **right** sensors observe the wall parallel to the current straight section; the controller selects the inside reference according to travel direction and uses the opposite side for close-wall protection. The **rear** sensor faces the space into which the vehicle reverses, providing a physical reference for reverse maneuvers and future recovery checks.

The OpenMV N6 is mounted above the chassis on the longitudinal centerline with a fixed forward angle. This position keeps both obstacle columns and the blue floor line inside its QVGA field of view while reducing occlusion by the front wheels and bumper. Its lower obstacle region supports red/green evasion, and its dedicated upper floor-line region provides the transition reference before the vehicle reaches a corner. The fixed bracket makes camera height and angle repeatable after transport; white balance, exposure, thresholds, and regions of interest are checked whenever field lighting changes.

| Sensor | Orientation | Field feature observed | Decision supported |
|---|---|---|---|
| Front VL53L8CX | Forward | Outer wall at the end of a straight | Edge approach, corner entry, and blue-line maneuver threshold |
| Rear VL53L8CX | Backward | Clearance behind the vehicle | Reverse clearance and recovery diagnosis |
| Left VL53L8CX | 90° left | Left wall along straights and corners | Clockwise wall following and left-side protection |
| Right VL53L8CX | 90° right | Right wall along straights and corners | Counterclockwise wall following and right-side protection |
| OpenMV N6 | Forward, elevated, fixed angle | Red/green columns and colored floor lines | Obstacle side selection, direction selection, and turn sequencing |

### 5.3 Robot Gallery

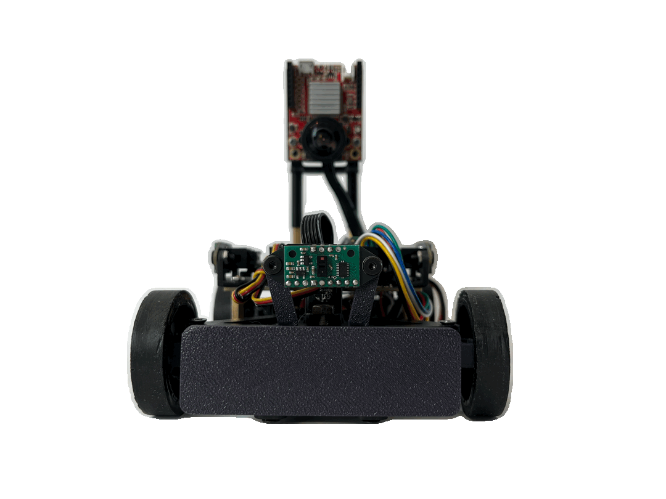
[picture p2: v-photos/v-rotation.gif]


<table  style="width: 100%;">
<tbody>
<tr>
<td>
<center><h4>Front</h4></center>
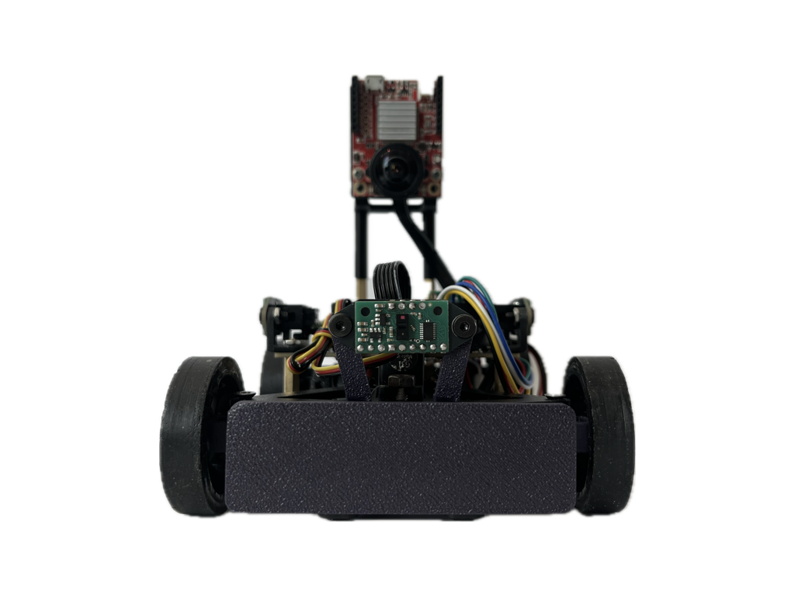
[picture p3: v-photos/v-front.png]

</td>
<td>
<center><h4>Back</h4></center>
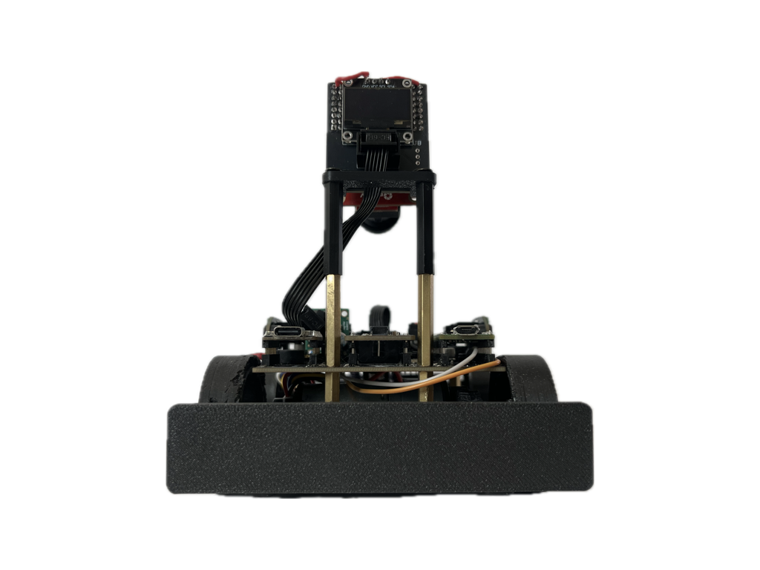
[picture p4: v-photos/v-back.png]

</td>
</tr>
<tr>
<td>
<center><h4>Right</h4></center>
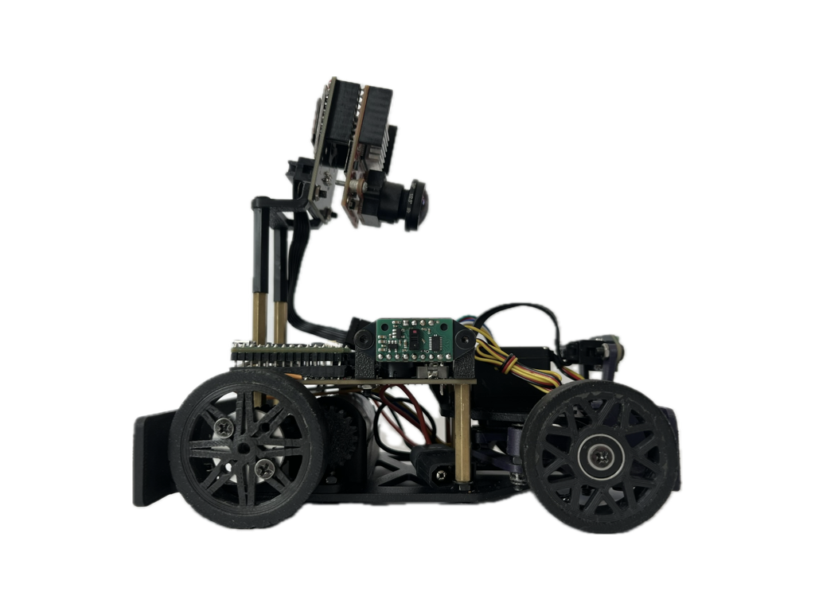
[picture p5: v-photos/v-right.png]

</td>
<td>
<center><h4>Left</h4></center>
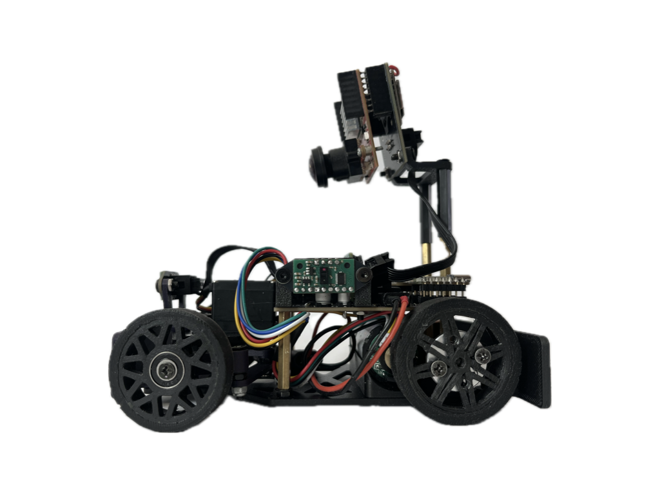
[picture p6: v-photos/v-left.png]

</td>
</tr>
</tbody>
</table>

---

## 6. Mobility Management 

### 6.1 Gearbox

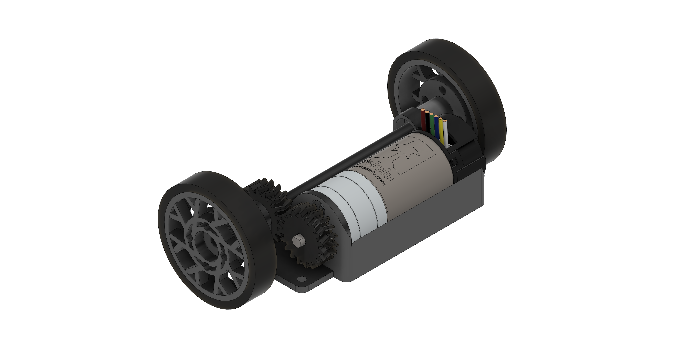
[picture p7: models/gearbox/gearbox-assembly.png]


The robot's transmission features a custom-designed gearbox, with the base and gears developed in CAD software and manufactured in-house. For fabrication, the team used a Creality K2 Plus Combo printer, chosen for its reliability in handling engineering-grade materials. The material selected was Polymaker PETG-CF (a carbon-fiber-infused PETG), prized for its high stiffness, dimensional stability, and excellent wear resistance, which are critical for durable mechanical components.

A key design feature is the use of double helical gears. This geometry was chosen over standard spur gears to ensure smoother, quieter power transmission with reduced vibration and superior load distribution. This significantly improves mechanical efficiency and component lifespan.

The drive axle consists of 4 mm steel shafts, which were custom-cut from rod stock. To ensure positive torque transfer from the gearbox to the wheels, the ends of the shafts were manually modified using a Dremel tool to create a "D" shape. This profile prevents slippage between the shaft and the wheel hub, a common failure point in high-torque applications.

| Part | Description | Image |
| --- | --- | --- |
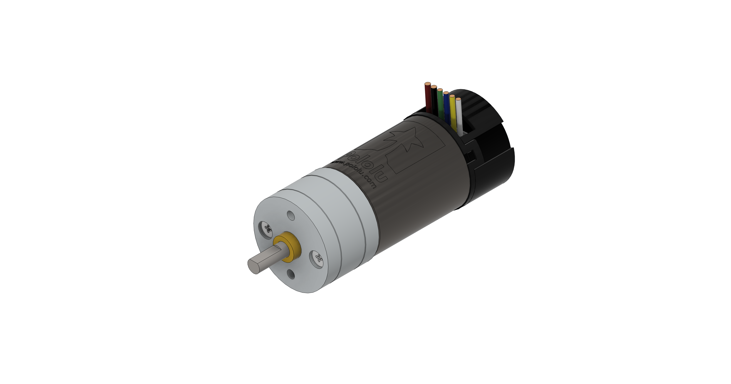
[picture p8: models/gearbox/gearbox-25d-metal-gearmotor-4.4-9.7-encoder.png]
| 6.1.1 Pololu 25D Motor and Encoder | The installed drive unit is the **Pololu 25D Metal Gearmotor 20.4:1 HP 12 V with 48 CPR Encoder, product #3203**. Its approximately 500 RPM no-load output provides the required speed while the integrated gearbox supplies the reduction before the custom transmission. The quadrature encoder supplies wheel-motion feedback for distance and speed control. | <picture style="display: block; margin: 0 auto;"></picture> |
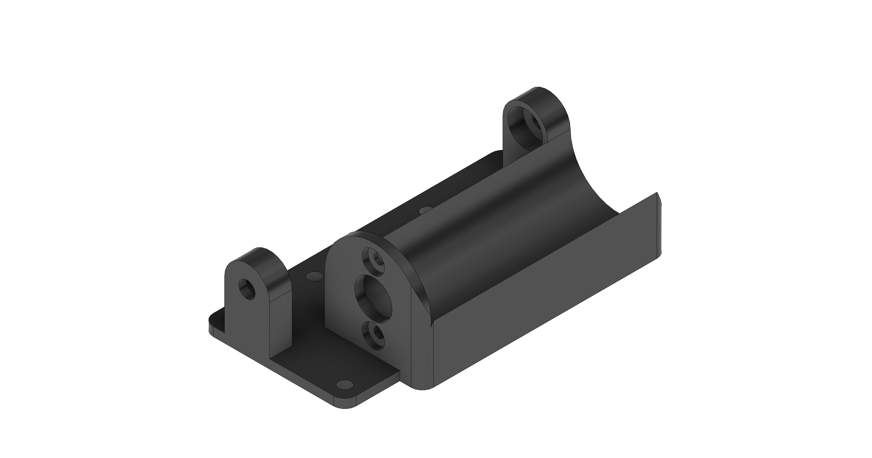
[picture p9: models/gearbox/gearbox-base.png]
| 6.1.2 Base | We designed the base of the gearbox so that the wheel axle is as close as possible to the steering axis in order to make tighter turns. | <picture style="display: block; margin: 0 auto;"></picture> |
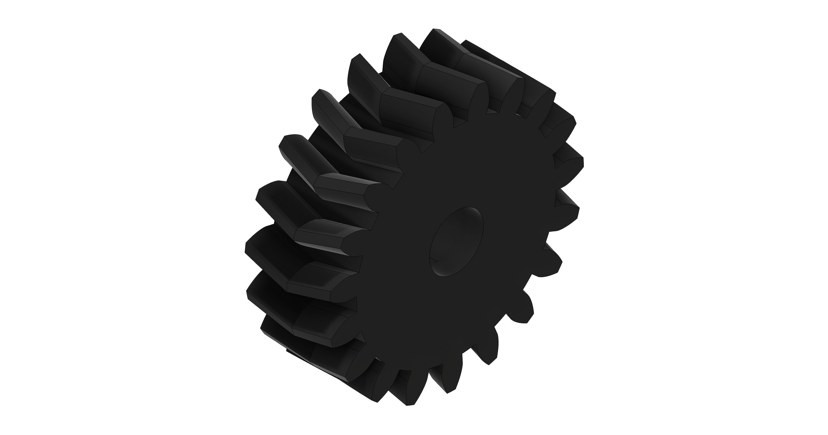
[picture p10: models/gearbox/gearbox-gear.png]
| 6.1.3 Gears | The custom-printed double-helical gears transfer power from the Pololu #3203 gearhead output to the rear axle. This external stage uses a **1:1 ratio**, so it preserves the motor's approximately 500 RPM no-load output and the torque delivered by its internal 20.4:1 gearbox. The external gears exist to place the motor compactly and transmit power to the axle, not to add another reduction. | <picture style="display: block; margin: 0 auto;"></picture> |
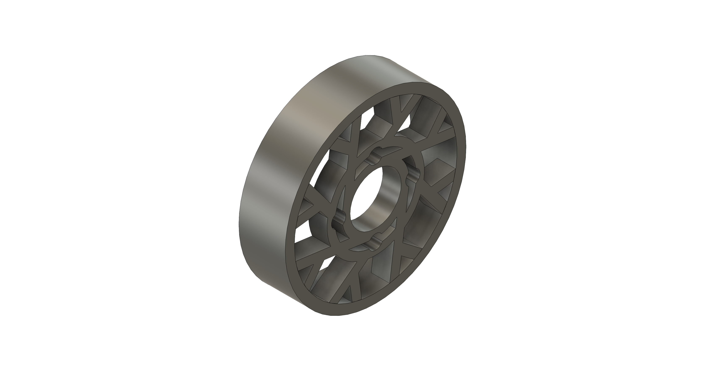
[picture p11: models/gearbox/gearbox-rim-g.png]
| 6.1.4 Rear Rim | The custom rear rim matches the larger driven-wheel diameter to the chassis ground clearance. Its D-profile hub provides positive torque transfer to the 4 mm axle, while the printed spoke structure keeps the part stiff without unnecessary material. The polyurethane tread supplies replaceable traction on the competition surface. | <picture style="display: block; margin: 0 auto;"></picture> |

The motor CAD asset retains an earlier `9.7` reference in its filename because the geometry was imported during prototyping. It is an envelope and assembly reference only; the installed competition motor and every drivetrain calculation use Pololu #3203 with its 20.4:1 internal gearbox.

### 6.2 Steering System

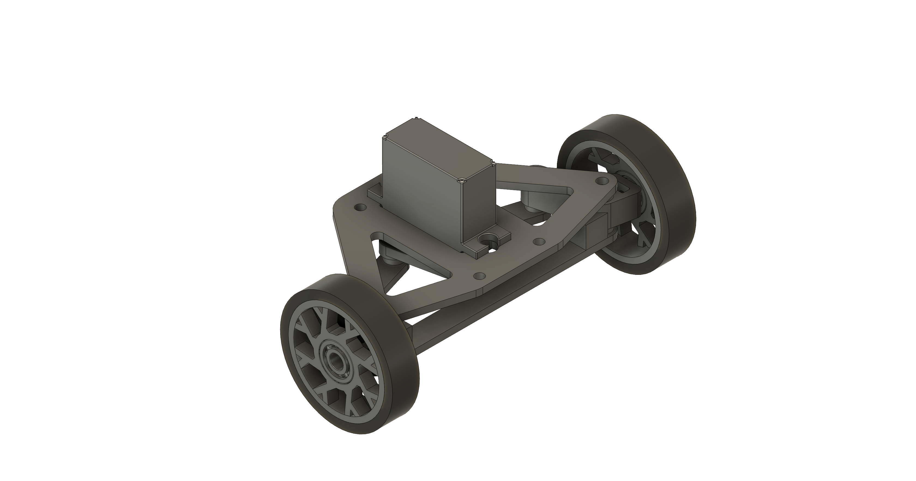
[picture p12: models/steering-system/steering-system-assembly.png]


For the steering system, the goal was to simplify the mechanism so it could be manufactured and repaired quickly. We selected Ackermann geometry so the inner wheel can turn farther than the outer wheel. This reduces geometric tire scrub during a turn, although tire deformation, axle coupling, surface grip, and alignment can still produce slip.

| Part | Description | Image |
| --- | --- | :---: |
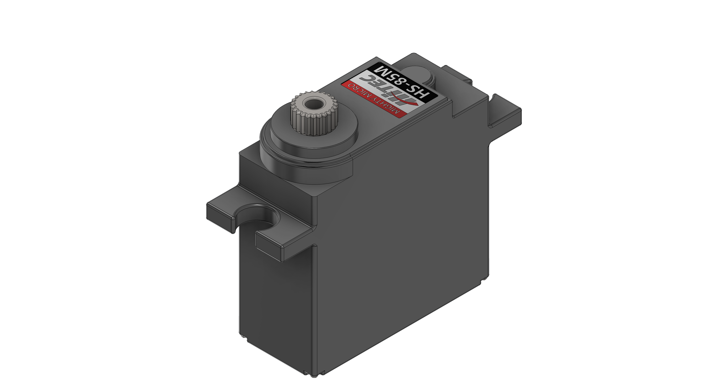
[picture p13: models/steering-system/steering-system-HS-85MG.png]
| 6.2.1 Servo HiTEC HS-85MG | We selected the HiTEC HS-85MG for our robot's Ackermann steering system, primarily due to its robust metal gears (MG). Unlike many standard or smaller servos that use plastic gears, the metal gearing provides the significantly enhanced durability and resistance to stripping that our steering mechanism requires. This is crucial for us to handle the mechanical loads, vibrations, and potential impacts inherent in the system's operation. We also find that this servo packs considerable torque and good precision into a compact "mighty mini" form factor, supported by a top ball bearing. This ensures it provides the strength we need to turn the wheels effectively while maintaining accurate steering angles, minimizing the excessive "slop" or backlash we might see in less robust options. For application, this blend of power, durability, and reliable accuracy in a small package makes it a superior choice over servos that could fail or wear quickly under the demands of steering. | <picture style="display: block; margin: 0 auto;">  </picture> |
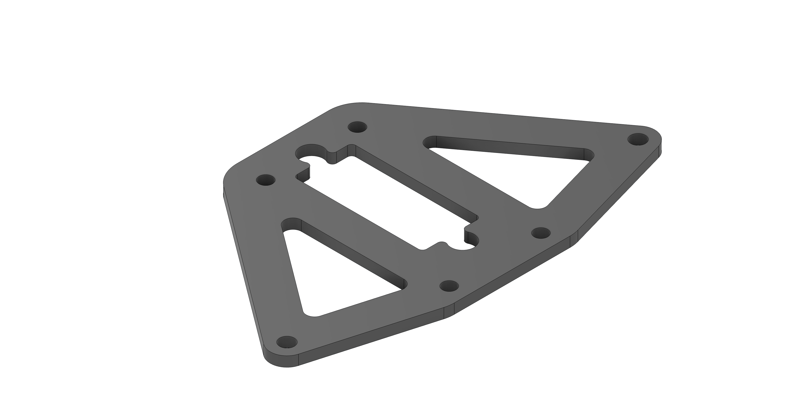
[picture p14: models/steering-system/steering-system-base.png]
| 6.2.2 Base | We designed the base around the servo, so that everything was symmetrical. We also designed the base to be modular and easily attach to the robot's chassis for easy repairs. This part is made out of stainless steel in order to balance the robot's center of mass. | <picture style="display: block; margin: 0 auto;">  </picture> |
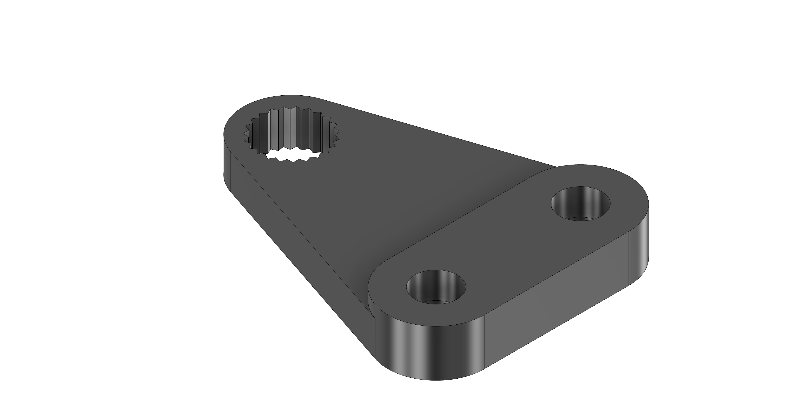
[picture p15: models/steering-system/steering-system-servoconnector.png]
| 6.2.3 Servo Connector | We designed the servo connector this way because, as an Ackermann system, the wheels needed to be connected independently of each other. If we used a single connector for the wheels, both would have the same turning angle, but by splitting it, each wheel would turn at a different angle. | <picture style="display: block; margin: 0 auto;">  </picture> |
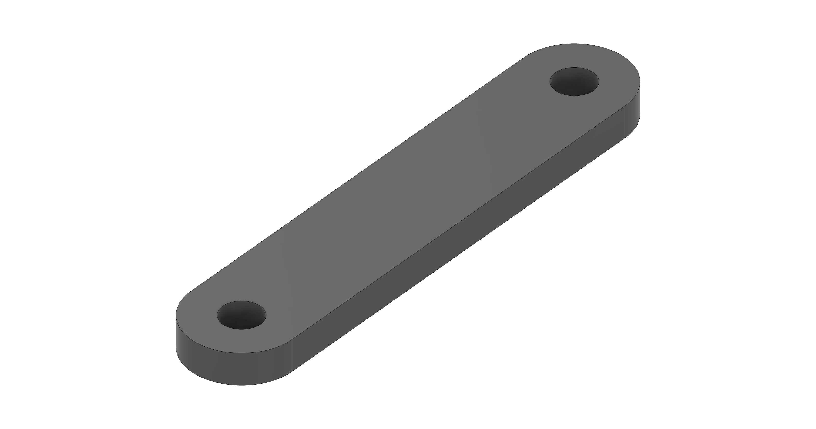
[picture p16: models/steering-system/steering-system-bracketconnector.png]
| 6.2.4 Bracket Connectors | As mentioned above, we used two connectors, one per wheel, so they rotated independently.| <picture style="display: block; margin: 0 auto;">  </picture> |
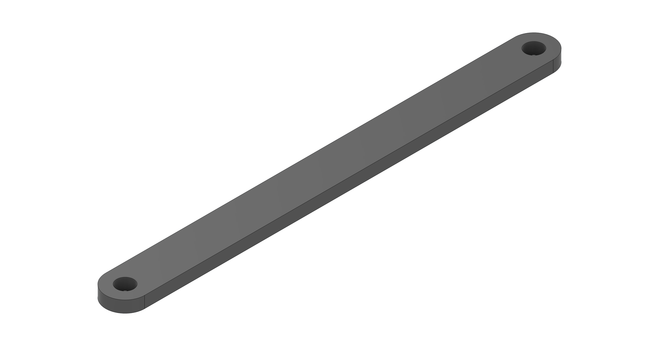
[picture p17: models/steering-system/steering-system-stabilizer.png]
| 6.2.5 Stabilizer | This stabilizer bar is to prevent the wheel brackets from having play and to make them more stable. | <picture style="display: block; margin: 0 auto;">  </picture> |
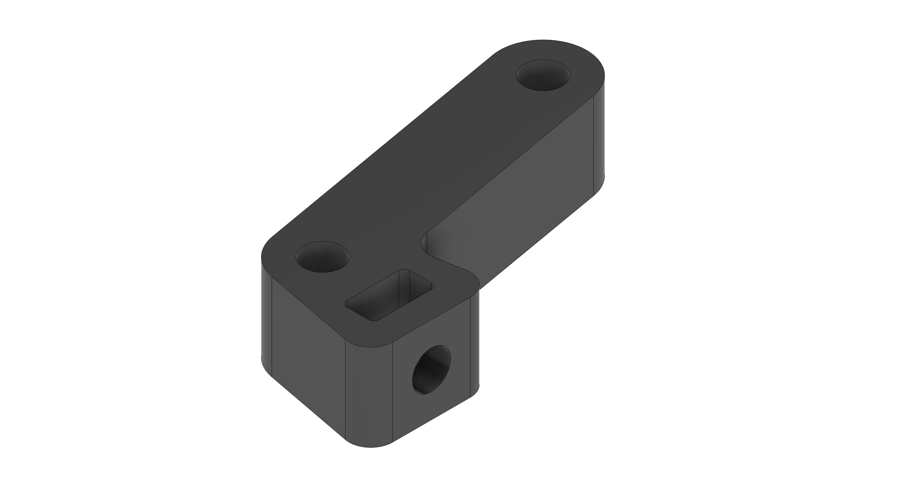
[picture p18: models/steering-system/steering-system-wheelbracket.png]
| 6.2.6 Wheel Bracket | We designed the wheel mount with an angle in order that the line projected collides in the center of the rear axis. | <picture style="display: block; margin: 0 auto;">  </picture> |
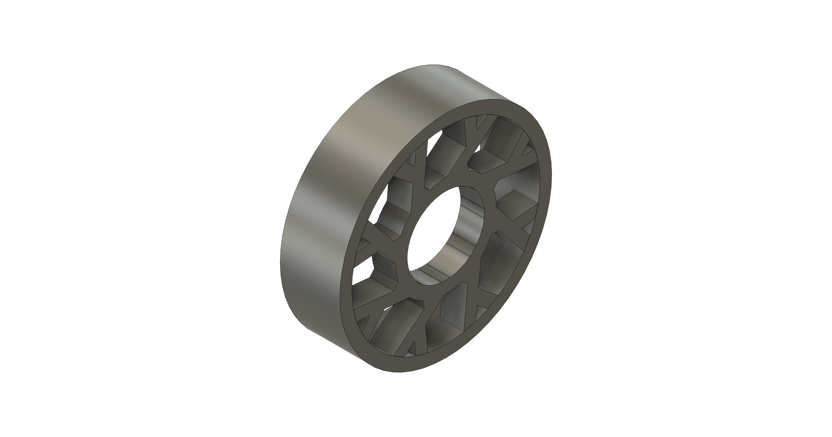
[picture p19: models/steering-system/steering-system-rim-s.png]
| 6.2.7 Rim S | The rim s represents the compact version of our wheel assembly, designed specifically to attach to the front wheel mounts via a bearing. This smaller variant is crucial for maintaining the robot's horizontal alignment, counterbalancing the weight of the larger rear drive wheels to achieve a perfectly level center of gravity. Engineered for low-friction rotation and high maneuverability, the rim features an optimized profile that reduces rotational inertia. Subsequently, we use a mold and A40 polyurethane resin to manufacture the rubber component. This process is shown in the following video: [WRO FutureEngineers Custom Wheels - chaBots NERV](https://youtu.be/8JH6QCOU_B0) | <picture style="display: block; margin: 0 auto;">  </picture>|

### 6.3 Camera Mount

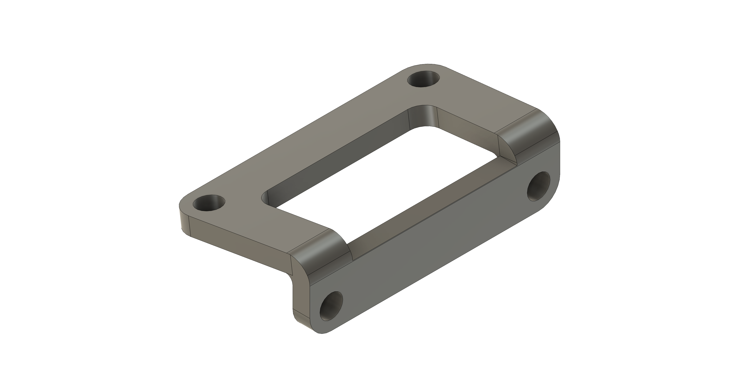
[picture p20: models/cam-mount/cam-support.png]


A simple fixed-angle bracket designed to mount the camera onto the robot chassis.

### 6.4 Chassis

| Part | Description | Image |
| --- | --- | :---: |
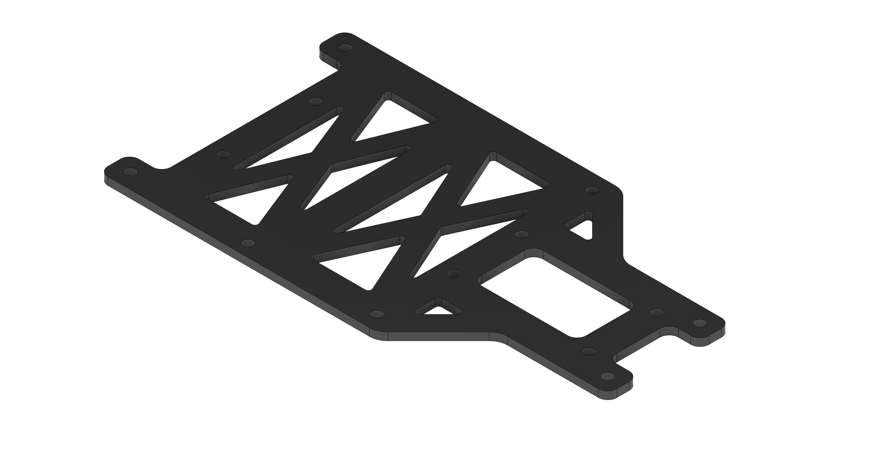
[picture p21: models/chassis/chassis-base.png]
| 6.4.1 Chassis Base | The chassis is the robot's main structure, as all other systems are mounted on it. A modular design was chosen to facilitate assembly and maintenance. The chassis is made of stainless steel. | <picture style="display: block; margin: 0 auto;">  </picture> |
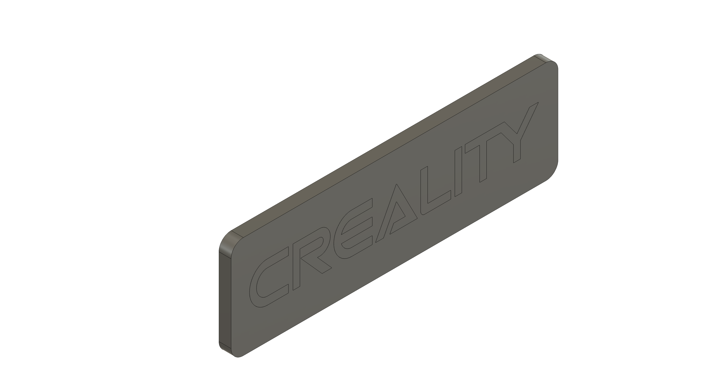
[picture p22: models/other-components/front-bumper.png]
| 6.4.2 Front Bumper | Designed for front-end integration, this custom bumper acts as a protective shield for the robot's chassis by absorbing direct frontal impacts and preventing damage to internal electronics or sensors during navigation. | <picture style="display: block; margin: 0 auto;">  </picture> |
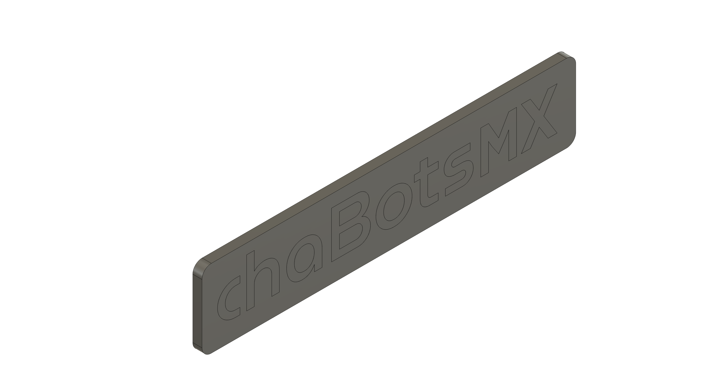
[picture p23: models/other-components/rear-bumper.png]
| 6.4.3 Rear Bumper | Designed for rear-end protection, this custom bumper shields the back of the chassis and internal components from impacts during reversing maneuvers or wall contact. | <picture style="display: block; margin: 0 auto;">  </picture> |

### 6.5 Assembly

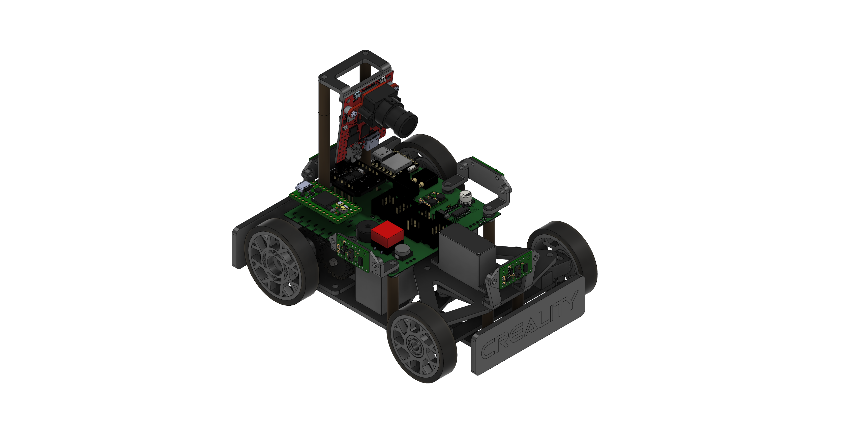
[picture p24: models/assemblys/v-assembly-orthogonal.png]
Robot Assembly Diagram


The steering system is mounted on the chassis using 20mm-high M3 posts. The gearbox is mounted directly to the rear of the chassis, and the main PCB is mounted on it using 30mm-high M3 posts. The OpenMV N6 camera base is mounted on the main PCB using 30mm-high M3 posts. The ToF sensors are connected on their PCBs which are mounted using 3D-printed supports.

<table style="width: 100%; border-collapse: collapse;">
  <tbody>
    <tr>
      <td style="width: 50%; padding: 5px;">
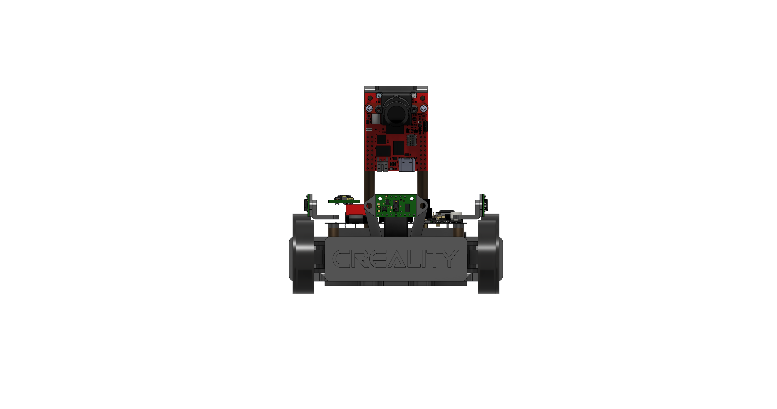
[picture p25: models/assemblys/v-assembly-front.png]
Vista Frontal
        
      </td>
      <td style="width: 50%; padding: 5px;">
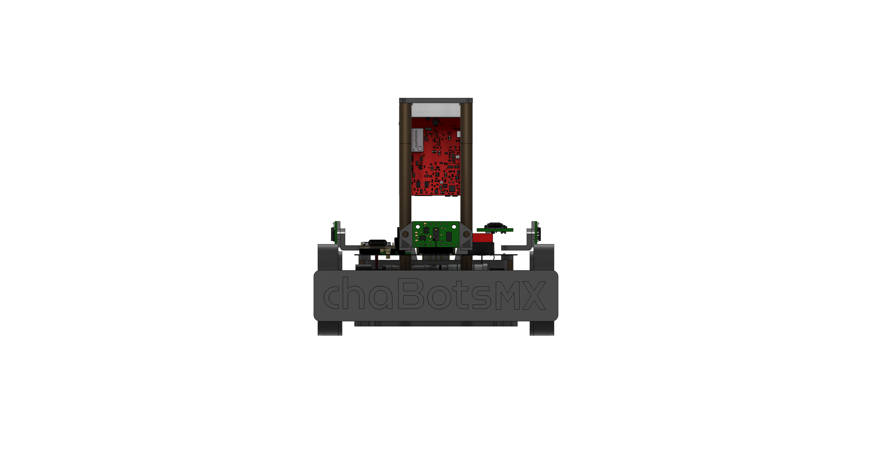
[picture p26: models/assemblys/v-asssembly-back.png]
Vista Trasera
        
      </td>
    </tr>
    <tr>
      <td style="width: 50%; padding: 5px;">
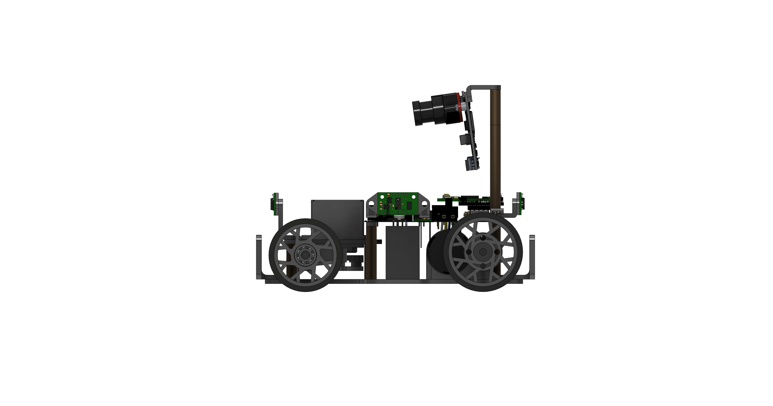
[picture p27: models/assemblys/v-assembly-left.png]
Vista Izquierda
        
      </td>
      <td style="width: 50%; padding: 5px;">
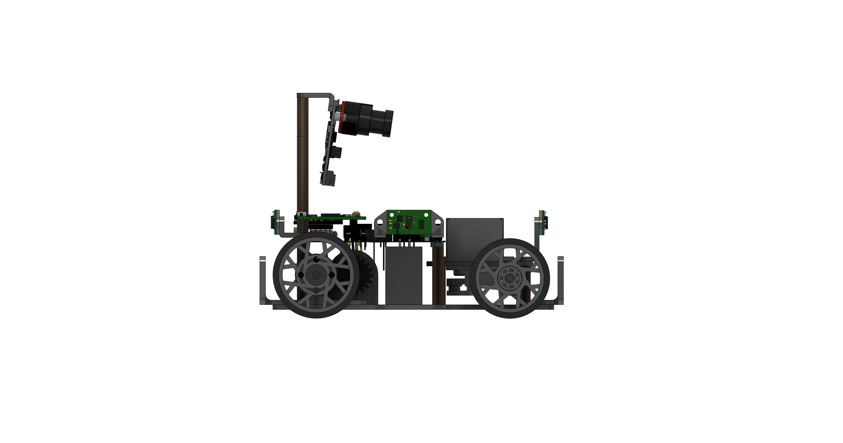
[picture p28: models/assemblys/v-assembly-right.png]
Vista Derecha
        
      </td>
    </tr>
    <tr>
      <td style="width: 50%; padding: 5px;">
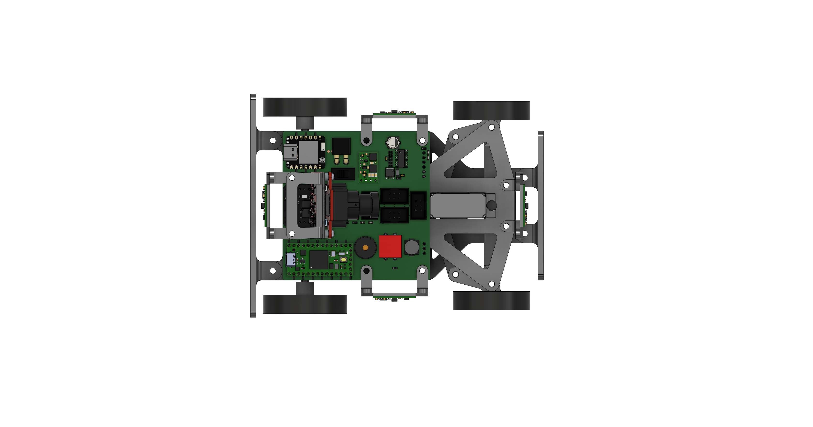
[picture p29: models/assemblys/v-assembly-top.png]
Vista Superior
        
      </td>
      <td style="width: 50%; padding: 5px;">
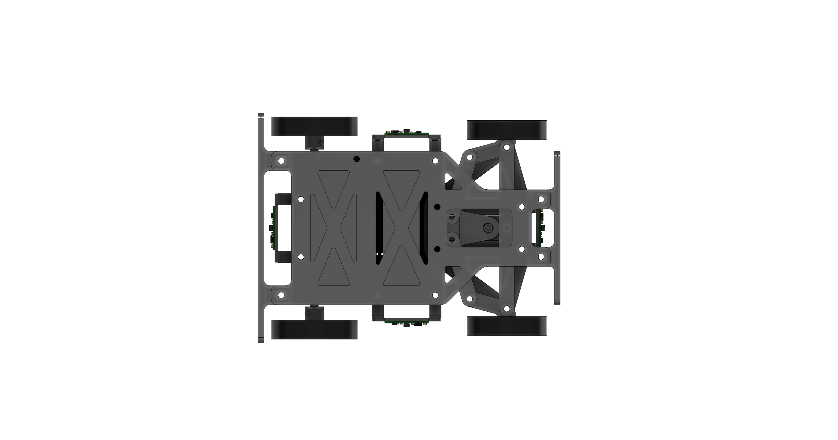
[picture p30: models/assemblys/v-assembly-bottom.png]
Vista Inferior
        
      </td>
    </tr>
  </tbody>
</table>

---

## 7. Power, Electronics and Sensor Management 

This section describes the hardware that is installed in the final robot and how it is connected. The alternatives, environmental tests, and reasons behind each sensor choice are documented once in [Section 4.3: Sensor Changes](#sensor-changes).

### System Responsibilities

| Device | Final role | Main connection |
|---|---|---|
| Teensy 4.0 | Main control, state machine, direct ToF acquisition, steering, motor control, encoder processing, and safety logic | SPI, UART, PWM, digital I/O |
| Seeed Studio XIAO ESP32-C6 | Development telemetry bridge | UART from Teensy; Wi-Fi only during development |
| OpenMV N6 | Detects red and green obstacles and blue-line references | UART to Teensy |
| BNO085 | Provides rotation-vector heading for turns and heading correction | UART to Teensy |
| Pololu #3203 encoder | Measures wheel motion for distance and speed estimation | Quadrature digital inputs |
| VNH7070AS | Drives the rear DC motor | PWM and direction signals |
| HiTEC HS-85MG | Controls the Ackermann steering mechanism | Servo PWM |

The XIAO can transmit telemetry during development. Wireless functions are disabled during official runs; the competition system does not depend on an external computer or network.

### Competition Configuration

| Subsystem | Competition configuration | Firmware or setting |
|---|---|---|
| Main controller | Teensy 4.0 | `src/src/open-main.cpp` for Open; `src/src/obstacles-main.cpp` for Obstacles |
| Distance sensing | Four VL53L8CX sensors connected to the Teensy SPI interface | `src/lib/TOF4Walls/`; 60 Hz initialization target |
| Vision | OpenMV N6 | Obstacle/blue-line packet to `Serial3` at 115200 baud |
| Heading | BNO085 | Rotation-vector yaw to `Serial4` at 115200 baud |
| Motion feedback | Pololu #3203 quadrature encoder | Quadrature inputs processed by `src/lib/Move/` |
| Drive | Pololu #3203, 20.4:1 HP 12 V, 500 RPM no-load, through VNH7070AS | PWM and direction from Teensy |
| Steering | HiTEC HS-85MG and Ackermann linkage | Servo PWM with calibrated map; command limited to ±25.94° |
| Battery | 3S LiPo, 11.1 V nominal, 1000 mAh | Battery rail for motor; regulated 5 V and 3.3 V rails |
| Development telemetry | Seeed Studio XIAO ESP32-C6 | `src/src/xiao-main.cpp`; not required for an official run |

### Firmware Build and Upload

Use PlatformIO from the repository's `src/` project directory, which contains the active `platformio.ini`. Each target compiles one firmware image; only the Open or Obstacles firmware is loaded on the Teensy for a given run.

```bash
# Open challenge firmware — Teensy 4.0
pio run -e teensy40

# Obstacles challenge firmware — Teensy 4.0
pio run -e teensy40_obstacles

# Development telemetry bridge — XIAO ESP32-C6
pio run -e xiao_esp32c6
```

To upload a selected target, append `-t upload` to its command. The OpenMV program is deployed separately with the OpenMV IDE; confirm that its serial packet format matches the active Teensy firmware before the run.

### Power Architecture and Consumption

The robot uses a 3S LiPo battery with a nominal voltage of 11.1 V. The electrical system is divided into three main power rails:

1. **Battery rail — 11.1 V nominal:** motor driver and drive motor.
2. **Regulated 5 V rail:** Teensy, XIAO ESP32-C6, OpenMV camera, RGB LED, encoders, and steering servo.
3. **Regulated 3.3 V rail:** four VL53L8CX ToF sensor modules.

The BNO085 IMU is powered from the Teensy's 3.3 V output and is therefore not connected to the external 3.3 V regulator.

Power is expressed in watts:

```math
P = V \times I
```

Energy stored in the battery is expressed in watt-hours:

```math
E = V \times Q_{\mathrm{Ah}}
```

For the 11.1 V, 1000 mAh battery:

```math
E = 11.1\,\mathrm{V} \times 1\,\mathrm{Ah} = 11.1\,\mathrm{Wh}
```

#### Component Power Budget

| Load | Supply | Normal or design current | Peak current used for design | Peak power | Basis |
|---|---:|---:|---:|---:|---|
| Teensy 4.0 | 5 V | 100 mA | 100 mA | 0.50 W | Manufacturer operating figure at 600 MHz |
| XIAO ESP32-C6 | 5 V | 250 mA | 250 mA | 1.25 W | Conservative rail-allocation value; Wi-Fi is disabled during official operation |
| WS2812B RGB LED | 5 V | 25 mA | 25 mA | 0.125 W | Configured-brightness design value; full-white current can be higher |
| OpenMV N6 | 5 V | 150 mA | 150 mA | 0.75 W | Full-power value from the OpenMV N6 specification |
| HS-85MG steering servo | 5 V | 240 mA | 1.2 A | 6.00 W | Published running current plus a conservative transient allowance; 1.2 A is not presented as a measured stall current |
| Four VL53L8CX carrier boards | 3.3 V | 400 mA total | 600 mA total | 1.98 W | Conservative carrier-board allocation of 100 mA typical and 150 mA peak per module |
| BNO085 IMU | Teensy 3.3 V output | 12.5 mA | 12.5 mA | 0.041 W | Manufacturer operating figure; excluded from the external 3.3 V rail total |
| Pololu #3203, 20.4:1 HP 12 V motor | Battery rail | 300 mA no-load | 1.5 A design operating current | 16.65 W at 11.1 V | Manufacturer no-load and approximately 5 A stall figures; 1.5 A is the conservative operating design point |

The motor's 1.5 A value is the expected high-load operating current used for the main power estimate. It must not be confused with the approximately 5 A stall current, which is treated separately as a short-duration transient.

#### 5 V Rail

The normal estimated current, including the servo's published running current, is:

```math
I_{5V,normal} = 0.100 + 0.250 + 0.025 + 0.150 + 0.240 = 0.765\,\mathrm{A}
```

```math
P_{5V,normal} = 5\,\mathrm{V} \times 0.765\,\mathrm{A} = 3.825\,\mathrm{W}
```

Using the 1.2 A servo transient as the design condition:

```math
I_{5V,peak} = 0.100 + 0.250 + 0.025 + 0.150 + 1.200 = 1.725\,\mathrm{A}
```

```math
P_{5V,peak} = 5\,\mathrm{V} \times 1.725\,\mathrm{A} = 8.625\,\mathrm{W}
```

A small additional margin is required for the BNO085 because it is powered through the Teensy's onboard 3.3 V regulator. Therefore, the practical 5 V design budget is approximately **1.73 A and 8.7 W**.

The 5 V rail uses a **Pololu D24V50F5** regulator, rated for approximately 5 A. At a 1.73 A output load, the regulator operates at approximately 35% of its nominal current capacity.

Assuming 90% efficiency:

```math
P_{in,5V} = \frac{8.7\,\mathrm{W}}{0.90} \approx 9.67\,\mathrm{W}
```

```math
P_{loss,5V} = 9.67 - 8.7 \approx 0.97\,\mathrm{W}
```

#### 3.3 V ToF Rail

Each VL53L8CX module uses approximately 100 mA during typical continuous ranging and may reach approximately 150 mA.

For four sensors:

```math
I_{3.3V,typical} = 4 \times 0.100 = 0.400\,\mathrm{A}
```

```math
P_{3.3V,typical} = 3.3\,\mathrm{V} \times 0.400\,\mathrm{A} = 1.32\,\mathrm{W}
```

For the peak design condition:

```math
I_{3.3V,peak} = 4 \times 0.150 = 0.600\,\mathrm{A}
```

```math
P_{3.3V,peak} = 3.3\,\mathrm{V} \times 0.600\,\mathrm{A} = 1.98\,\mathrm{W}
```

The ToF rail uses a **Pololu D24V10F3**, rated for approximately 1 A. A 600 mA peak load uses 60% of its nominal current capacity.

Assuming 87% efficiency:

```math
P_{in,3.3V} = \frac{1.98\,\mathrm{W}}{0.87} \approx 2.28\,\mathrm{W}
```

```math
P_{loss,3.3V} = 2.28 - 1.98 \approx 0.30\,\mathrm{W}
```

Because the VL53L8CX carrier boards are powered close to their minimum accepted input voltage, the voltage must also be measured directly at the sensor connectors under maximum load to verify that wiring losses do not reduce it excessively.

#### Motor Rail

The motor is connected to the 3S battery through the VNH7070AS motor driver.

At the selected 1.5 A design operating current and the battery's nominal voltage:

```math
P_{motor} = 11.1\,\mathrm{V} \times 1.5\,\mathrm{A} = 16.65\,\mathrm{W}
```

At stall:

```math
P_{motor,stall} = 11.1\,\mathrm{V} \times 5\,\mathrm{A} = 55.5\,\mathrm{W}
```

Stall is not a normal operating condition, but it must be considered when selecting the battery, motor driver, wiring, connectors, switch, and protection system.

#### Estimated Total Battery Load

Assuming both regulators are connected directly to the battery:

| Section | Output power | Estimated battery input power | Battery current at 11.1 V |
|---|---:|---:|---:|
| 5 V regulated rail | 8.7 W | 9.67 W | 0.87 A |
| 3.3 V regulated rail | 1.98 W | 2.28 W | 0.21 A |
| Motor at design load | 16.65 W | 16.65 W | 1.50 A |
| **Estimated total** | — | **28.60 W** | **2.58 A** |

This estimate does not yet include the motor driver's conduction losses, regulator quiescent current, wiring losses, or battery voltage sag. The real battery input will therefore be slightly higher.

With an ideal 11.1 Wh battery:

```math
t_{\mathrm{ideal}} = \frac{11.1\,\mathrm{Wh}}{28.60\,\mathrm{W}} = 0.388\,\mathrm{h} \approx 23.3\,\mathrm{minutes}
```

This value is only a theoretical continuous-load estimate. Real runtime will be lower because of acceleration peaks, steering activity, battery discharge characteristics, voltage sag, and the required safety reserve.

During a motor stall, the complete system could temporarily demand approximately:

```math
I_{stall,total} \approx 5.0 + 0.87 + 0.21 = 6.08\,\mathrm{A}
```

Therefore, the 1000 mAh battery must support more than 6.08 A without excessive voltage drop. This corresponds to an absolute theoretical minimum of approximately 6.08C, although a substantially higher battery discharge rating should be used to provide adequate margin.

#### Power Integrity and Noise Control

Motor and servo current transients can introduce voltage drops and electrical noise into the logic and sensor rails. The PCB therefore uses:

- Local decoupling capacitors near each controller and sensor connector.
- Bulk capacitance close to the servo and regulator outputs.
- Short and wide high-current traces.
- Separate high-current return paths for the motor and servo.
- Ground pours connected with stitching vias.
- A common ground reference between controllers and sensors.
- Physical separation between motor-current paths and sensitive sensor signals.
- Voltage and current measurements under acceleration, hard steering, and motor-stall test conditions.

#### Theoretical Operating Checks

| Test condition | Battery voltage | Battery current | 5 V rail | 3.3 V rail | Expected behavior / acceptance criterion |
|---|---:|---:|---:|---:|---|
| Electronics idle | ~11.1 V | ~0.15 A | ~0.20 A | ~0.02 A | Rails remain stable and no component heats abnormally |
| Sensors and camera active | ~11.1 V | ~0.40 A | ~0.43 A | ~0.40 A | Sensor streams remain continuous without controller resets |
| Motor running straight | ~11.0 V | ~1.20 A | ~0.43 A | ~0.40 A | Motor driver remains within its safe operating temperature |
| Maximum steering movement | ~11.0 V | ~1.50 A peak | ~1.75 A peak | ~0.40 A | The 5 V rail remains regulated during the servo transient |
| Acceleration from rest | ~10.8 V | ~3.50 A peak | ~0.43 A | ~0.40 A | The 3.3 V sensor rail remains stable despite motor noise |
| Brief controlled motor stall | ~10.5 V | ~6.10 A peak | ~0.88 A peak | ~0.40 A | Protection operates without PCB or wiring damage; this is not a normal run condition |

Component values were taken from the manufacturers' documentation for the [Pololu D24V50F5](https://www.pololu.com/product/2851), [Pololu D24V10F3](https://www.pololu.com/product/2830), [Pololu VL53L8CX carrier](https://www.pololu.com/product/3419), [Teensy 4.0](https://www.pjrc.com/store/teensy40.html), [OpenMV N6](https://openmv.io/products/openmv-n6), [HiTEC HS-85MG](https://www.hiteccs.com/actuators/product-details/HS-85MG), and [Pololu 25D HP motor](https://www.pololu.com/product/3203/resources). Conservative or assumed values are identified in the table and will be replaced by measurements from the assembled robot.

### Main PCB

A single two-layer PCB integrates the Teensy 4.0, XIAO ESP32-C6, VNH7070AS driver, servo control, power input, feedback devices, and sensor connectors. Its **8 × 8 cm** size fits the reduced chassis and replaces the multiple-board arrangement used in the previous robot.

The board is mounted at the top of the chassis. This shortens wiring and makes the electronics accessible without disassembling the drivetrain.

<table style="width: 100%; table-layout: fixed;">
<tr>
<td>
The board uses an XT30 battery connector and includes the main controller interfaces, motor and servo outputs, sensor headers, and protection components. Ground pours on both layers, stitching vias, short return paths, and careful placement allow reliable high-baud-rate communication even with the motor close to the electronics.
</td>
<td>
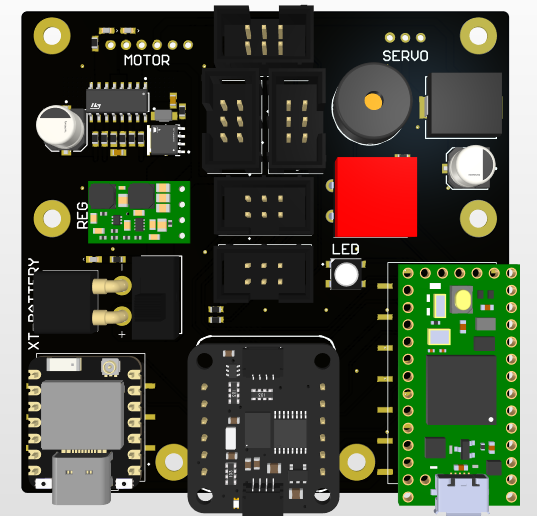
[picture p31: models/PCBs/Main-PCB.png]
Main robot PCB

</td>
</tr>
</table>

### Schematic Overview

The [Electronics](Electronics/) directory contains the editable Altium projects, schematic PDFs, PCB layouts, STEP models, and Gerber archives for the main board and the camera and ToF interface boards.

| Board | Schematic PDFs | Editable project and PCB layout | Manufacturing files | 3D model |
|---|---|---|---|---|
| Main PCB and motor driver | [Main schematic](https://github.com/chaBotsMX/chaBots-Tuneados-WRO-Future-Engineers-2026/blob/main/Electronics/main-pcb/WRO-MAIN.pdf) · [H-bridge schematic](https://github.com/chaBotsMX/chaBots-Tuneados-WRO-Future-Engineers-2026/blob/main/Electronics/main-pcb/H-BRIDGE-SCH.pdf) | [Altium project](Electronics/main-pcb/WRO.PrjPcb) · [PCB layout](Electronics/main-pcb/MAIN-PCB.PcbDoc) | [Gerber archive](Electronics/main-pcb/MAIN-GERBER.rar) | [STEP](Electronics/main-pcb/MAINWRO-PCB.STEP) |
| Camera interface PCB | [Camera schematic](https://github.com/chaBotsMX/chaBots-Tuneados-WRO-Future-Engineers-2026/blob/main/Electronics/cam-pcb/CAM-SCH.pdf) | [Altium project](Electronics/cam-pcb/WRO-CAMERA.PrjPcb) · [PCB layout](Electronics/cam-pcb/CAM-PCB.PcbDoc) | [Gerber archive](Electronics/cam-pcb/CAMERA-GERBER.rar) | [STEP](Electronics/cam-pcb/CAM-PCB.step) |
| ToF interface PCB | [ToF schematic](https://github.com/chaBotsMX/chaBots-Tuneados-WRO-Future-Engineers-2026/blob/main/Electronics/tof-pcb/TOF-SCH.pdf) | [Altium project](Electronics/tof-pcb/WRO-TOF.PrjPcb) · [PCB layout](Electronics/tof-pcb/TOF-PCBPcbDoc.PcbDoc) | [Gerber archive](Electronics/tof-pcb/TOF-GERBER.rar) | [STEP](Electronics/tof-pcb/TOF-PCB.step) |

The PDFs provide readable circuit references without requiring a PCB editor. Each board folder also includes editable `.SchDoc` schematic files and PNG previews. Open the `.PrjPcb` project in Altium Designer to work with its schematic and layout; extract the `.rar` archive to access the supplied Gerber files. The STEP models support mechanical integration with the chassis and mounts.

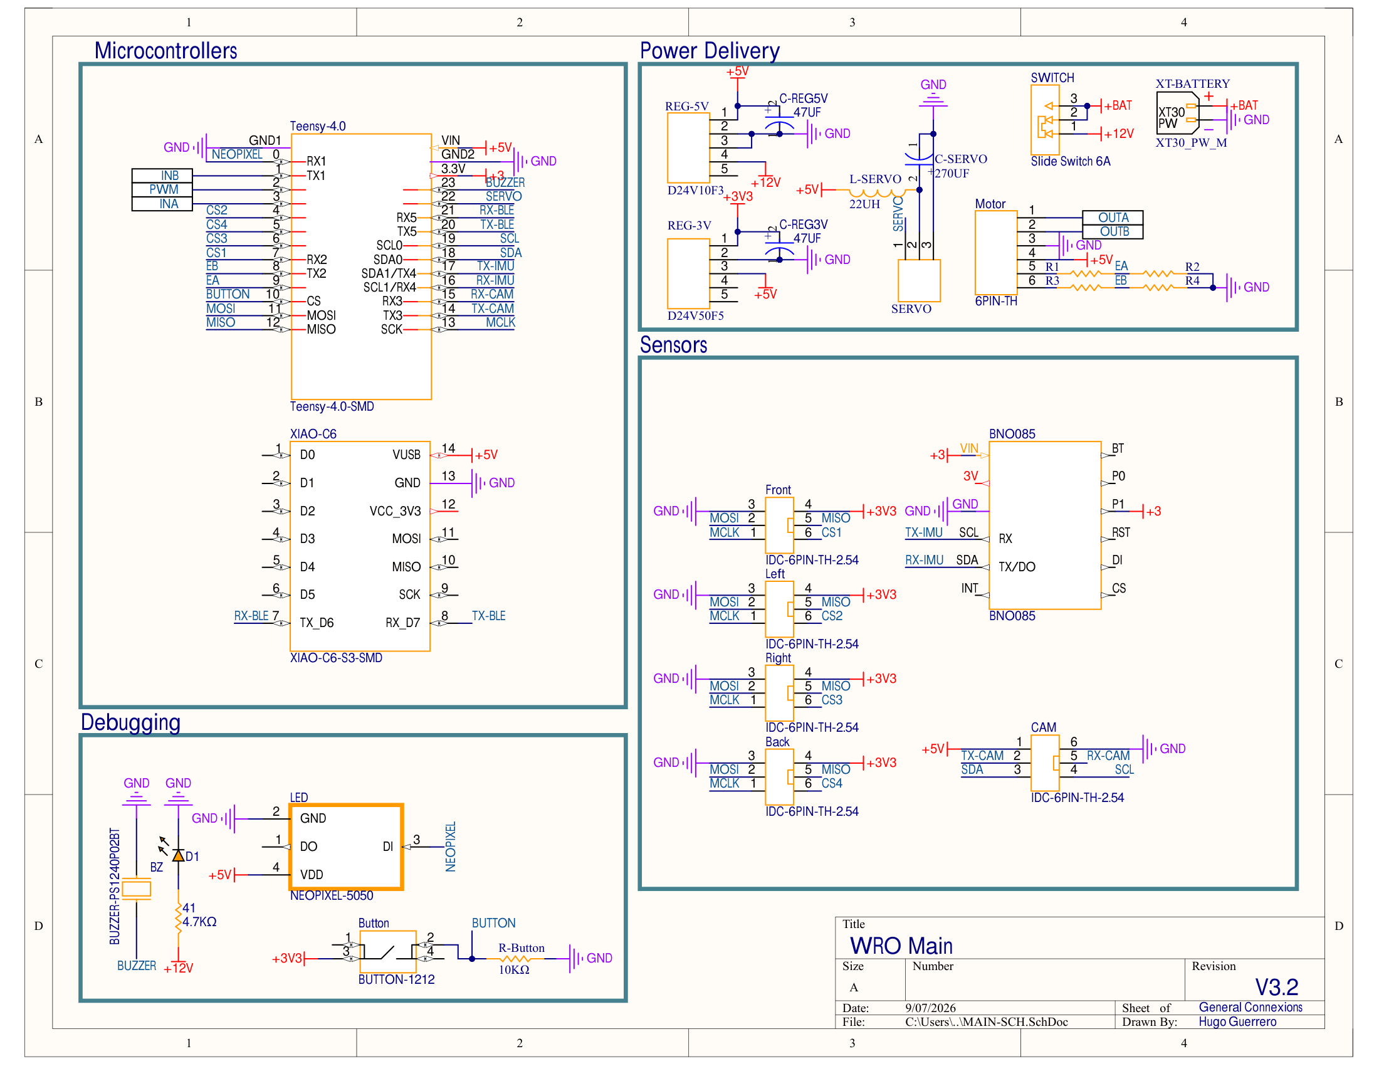
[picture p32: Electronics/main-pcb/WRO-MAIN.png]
Complete PCB schematic


<table style="width: 100%; table-layout: fixed;">
<tr>
<td>
<h4>Microcontrollers</h4>
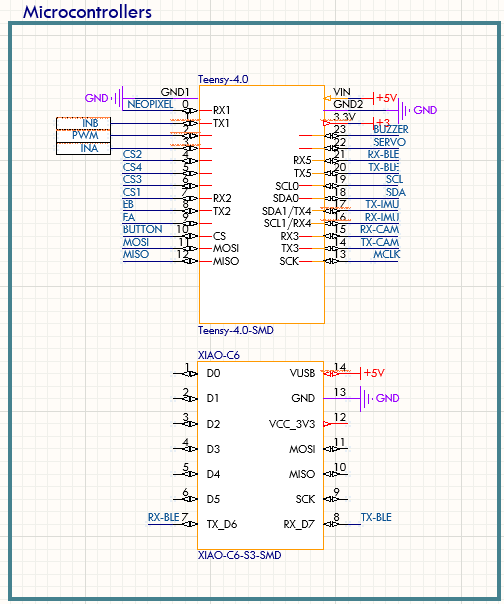
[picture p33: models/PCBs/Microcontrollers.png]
Microcontroller schematic

<p style="font-size: 0.9em; margin-top: 0.5em;">Logic connections for the Teensy 4.0 and Seeed Studio XIAO ESP32-C6.</p>
</td>
</tr>
<tr>
<td>
<h4>Power Delivery</h4>
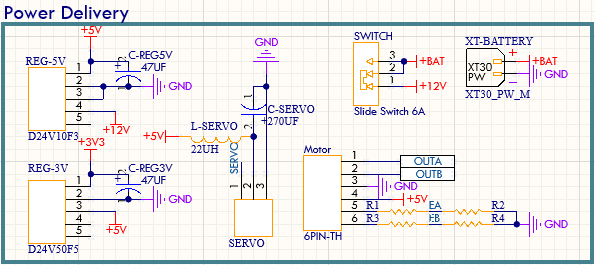
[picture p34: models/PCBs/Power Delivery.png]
Power-delivery schematic

<p style="font-size: 0.9em; margin-top: 0.5em;">XT30 battery connector, 6 A slide switch, Pololu D24V50F5 5 V regulator, Pololu D24V10F3 3.3 V regulator, filtered servo output, and motor output.</p>
</td>
</tr>
<tr>
<td>
<h4>Debugging and Feedback</h4>
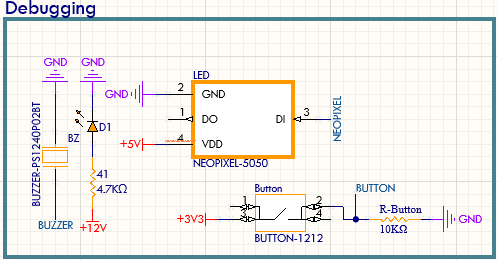
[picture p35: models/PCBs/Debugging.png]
Debugging schematic

<p style="font-size: 0.9em; margin-top: 0.5em;">Buzzer, power LED, start button, and programmable RGB LED.</p>
</td>
</tr>
<tr>
<td>
<h4>Sensors</h4>
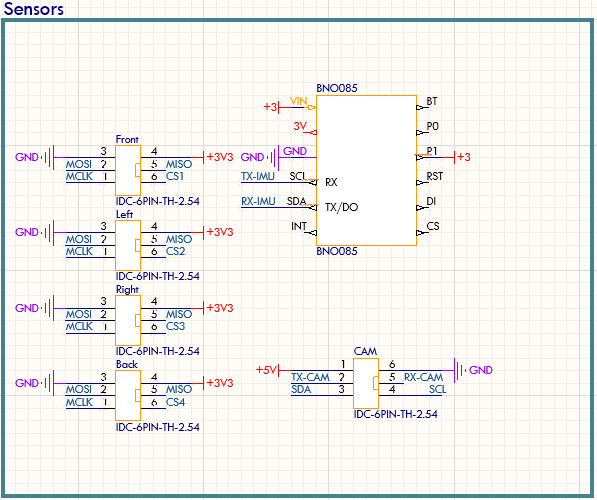
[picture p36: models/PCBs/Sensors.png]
Sensor schematic

<p style="font-size: 0.9em; margin-top: 0.5em;">IDC connections for the ToF boards, UART camera connection, and the BNO085 mounted directly on the PCB.</p>
</td>
</tr>
</table>

### BNO085 IMU

The BNO085 replaced the BNO055. We use its rotation-vector output over UART because it produced lower drift and required less repeated calibration in our tests. The dedicated serial link keeps heading traffic separate from the SPI ToF acquisition and gives the Teensy a direct heading stream. The comparison and environmental reasoning are in [Section 4.3.3](#position-and-movement).

### Teensy 4.0

- **Role:** main real-time controller for navigation, PWM generation, encoder processing, sensor timing, and safety interlocks.
- **Power integrity:** local 0.1 µF decoupling and a 10 µF bulk capacitor are placed close to the controller supply.
- **I/O:** SPI acquires all four VL53L8CX streams directly; UART receives the BNO085 and OpenMV N6 data; quadrature inputs read the motor encoder; dedicated PWM and direction lines drive the VNH7070AS and steering servo.
- **Signal integrity:** short digital runs and optional 33–100 Ω series resistors reduce ringing on fast control signals.

### VNH7070AS Motor-Driver Stage

The VNH7070AS full bridge is integrated directly into the PCB because a suitable compact module was not available. It provides the current capacity needed by the rear motor while leaving voltage and thermal headroom.

- **Interface:** direction, PWM, enable, current-sense, and fault signals connect to the Teensy.
- **Decoupling:** bulk capacitance is placed beside the driver, with local 100 nF ceramic capacitors and a TVS device on the motor supply.
- **EMI control:** motor leads are kept short and twisted; an RC snubber can be fitted if testing shows excessive brush noise.
- **Thermal path:** a copper area and thermal vias spread heat from the exposed pad.

### Connectors and Peripherals

- The servo header is supplied from the regulated 5 V rail with its return path routed beside the supply trace.
- IDC connectors make the four ToF boards removable and reduce wiring mistakes.
- Dedicated headers expose the OpenMV UART, BNO085 UART, and ToF SPI connections for diagnosis.
- The buzzer, status LEDs, RGB LED, and start button provide feedback without an external display.
- The OpenMV N6 can be calibrated and inspected through USB-C and the OpenMV IDE.

## 8. Software Architecture and Control 

The robot’s code was completely remade from last year. This change was necessary because the system architecture is now different, but also because last year’s software was not as well structured as we wanted.

Last year, the robot used a Raspberry Pi as the main processing unit, while the Teensy 4.0 worked mostly as a low-level slave for motor control. This year, we moved to a simpler and more deterministic architecture. The Teensy 4.0 is now the main controller, while the Seeed Studio XIAO ESP32-C6 is used only for wireless debugging during development.

For this year’s code, we are focusing on improving every aspect of the software, especially:

- Better code structure

- More reliable sensor communication

- Cleaner libraries

- More consistent variable names

- Easier debugging

- Better separation between sensing, control, and actuation

The current release candidate implements both competition modes through shared sensing, motion, steering, and safety modules. Remaining work is tracked as field validation and tuning rather than as a second software architecture.

---

### 8.1 Seeed Studio XIAO ESP32-C6

The XIAO ESP32-C6 is a development-only telemetry bridge in the current repository. Its firmware (`src/src/xiao-main.cpp`) validates fixed telemetry frames received from the Teensy over UART and publishes the latest valid frame to the debugging application over Wi-Fi.

The XIAO is not part of the control loop for an official run: it does not acquire ToF data, generate steering commands, or drive the motor. Official operation remains autonomous on the Teensy, with wireless telemetry disabled.

---
### 8.2 Teensy 4.0

The Teensy 4.0 is the real-time controller for both competition modes. It initializes the BNO085 and four VL53L8CX sensors, reads OpenMV packets, processes encoder feedback, controls the VNH7070AS drive stage and steering servo, and executes the selected state machine.

The two entry points are `src/src/open-main.cpp` and `src/src/obstacles-main.cpp`. Both share the `Robot` facade and the sensor, motion, trajectory, and Ackermann libraries under `src/lib/`; their loop calls select the Open or Obstacles state machine.

---
### 8.2.1 Direct ToF Acquisition and Startup

The current firmware initializes the four VL53L8CX sensors directly from the Teensy SPI interface through `TOF4Walls`. It uses one front, rear, left, and right measurement stream; the navigation layer receives normalized millimeter values.

A new reading is valid only when it is non-negative, below 3000 mm, and no older than the configured 50 ms sensor timeout. Invalid or stale readings are replaced by an invalid sentinel before wall-following or obstacle logic uses them.

Startup proceeds in this order:

1. Initialize serial ports and the motor interface.
2. Initialize the BNO085; on failure, the Teensy performs a controlled software reset.
3. Initialize the four VL53L8CX sensors at the configured 60 Hz; on failure, the Teensy performs a controlled software reset.
4. Initialize the user interface and steering actuator, then wait for the start button while fresh sensor activity is shown locally.
5. Capture the initial heading as the IMU setpoint and enter the selected state machine.

The camera is not a startup interlock in the current firmware. If no fresh camera packet is available during the Obstacles mode, the controller continues its non-vision behavior; this is recorded as a known limitation in [Section 10](#testing-validation).

---
### 8.2.1.1 Pre-Competition Calibration

Perform these checks in order before a documented run:

1. **Steering center — every assembly:** Command the neutral steering position, attach the linkage without preload, and confirm both wheels are centered and clear the chassis through their full travel.
2. **BNO085 heading — every power cycle:** Keep the vehicle stationary during initialization, then set the current yaw as the reference heading immediately before the start button is pressed.
3. **Encoder scale — after any wheel, tire, gearbox, or encoder change:** Compare commanded travel with measured straight-line travel and update the distance-per-count calibration only after recording the error.
4. **ToF array — every setup:** Confirm front, rear, left, and right readings are fresh and plausible at a known wall distance; inspect the mounting direction after transporting the robot.
5. **OpenMV N6 — every lighting change:** Load the competition vision program, set the experimental white-balance control and color thresholds, verify the region of interest, and confirm the required obstacle and blue-line packets over UART.
6. **Wall reference and evasion — every field change:** Verify the selected wall distance, side-wall protection threshold, and tangential-image parameters with low-speed passes before full-speed runs.

The mechanical steering map is retained between runs unless the linkage is disturbed. Encoder scale is retained only while the wheel and drivetrain configuration remain unchanged.

---
### 8.2.2 Motion, Steering, and State Control

The active firmware keeps all vehicle decisions in the Robot, Move, TrajectoryController, and AckermannController libraries. The entry-point files contain only initialization and their selected Open or Obstacles loop.

| Function | Current implementation |
|---|---|
| Encoder distance | Move converts quadrature encoder ticks into travel. State transitions use the distance accumulated since the relevant reset point. |
| Wall following | The Stanley controller combines the selected side-wall error with normalized IMU heading error. Clockwise runs use the left wall; counterclockwise runs use the right wall. |
| Steering | AckermannController limits the requested angle to ±25.94° and maps it through the calibrated servo-offset table. |
| Open direction | The Open camera line ID selects direction: ID 2 selects clockwise; the other supported start condition selects counterclockwise. |
| Open turn | The IMU reference changes by 90° for the selected direction. The turn completes when the absolute heading error is below 5°. |
| Obstacles response | Fresh N6 obstacle data selects the tangential controller; a close image-space obstacle starts the recovery sequence. |
| Blue-line turn | A stable blue-line detection arms the approach, reverse, and post-reverse states described in Section 9. |

#### State Dispatch and Transitions

The Obstacles dispatcher calls only the behavior associated with the active state:

```cpp
if (taskStatus == TASK::EVADE_UNTIL_EDGE) {
    executeEvadeUntilEdge();
} else if (taskStatus == TASK::APPROACH_BLUE_LINE) {
    executeApproachBlueLine();
} else if (taskStatus == TASK::REVERSE_AFTER_BLUE_LINE) {
    executeReverseAfterBlueLine();
} else if (taskStatus == TASK::FORWARD_AFTER_REVERSE) {
    executeForwardAfterReverse();
}
```

The state variable therefore selects the current objective, while each state contains only the sensor conditions and actuator commands required for that objective. A transition changes `taskStatus`; on the next loop iteration, the dispatcher immediately begins executing the new behavior.

Open turning illustrates how a sensor condition produces a state transition:

```cpp
if (abs(imu.getError()) < OPEN_TURN_ERROR_THRESHOLD_DEG) {
    if (lapCount != 11) {
        setFollowWall();
        lapCount++;
    } else {
        setOpenEnding();
    }
}
```

The robot remains in `OPEN_TURN` while its heading error is 5° or greater. Once aligned, it either starts the next wall-following segment or enters `OPEN_ENDING` after the twelfth turn.

The Stanley controller is:

```math
\theta = k_h\,\mathrm{wrap180}(e_{imu}) + \frac{180}{\pi}\,\mathrm{atan2}\left(k_s e_{wall}, v + 1\right)
```

where `e_wall` is the selected wall-distance error, `e_imu` is the IMU heading error, and `v` is the current speed. The requested steering value is constrained by the Ackermann controller before it reaches the servo.

```cpp
float angularError = wrap180(imuError);
float lateralCorrection = degrees(
    atan2(stanleyGain * wallError, speed + 1.0f)
);
return headingGain * angularError + lateralCorrection;
```

The heading term keeps the robot parallel to the intended track direction, while the wall term moves the robot toward the desired lateral clearance. Speed reduces the lateral correction so the vehicle does not overreact at higher velocity.

The resulting vehicle angle is converted into a safe servo command by the Ackermann layer:

```cpp
angle = constrain(
    angle,
    -MAX_ACKERMANN_ANGLE,
    MAX_ACKERMANN_ANGLE
);
float servoOffset = interpolateServoOffset(angle);
if (angle < 0.0f) {
    servoOffset = -servoOffset;
}
steeringServo.write(IDLE_STEERING_ANGLE + servoOffset);
```

Constraining the request protects the mechanical steering range. The interpolation table then converts a desired vehicle angle into the calibrated servo displacement required by the linkage.

### 8.2.3 Current Motion Profiles

| Open state | Distance | Maximum speed | Acceleration / deceleration |
|---|---:|---:|---:|
| Initial straight | 95 cm | 50 cm/s | 30 cm/s² |
| Wall-following segment | 130 cm | 90 cm/s | 30 cm/s² |
| Final segment | 40 cm | 30 cm/s | 60 cm/s² |

These values are firmware parameters in ControlValues.h. The validation matrices in Section 10 associate each field result with the exact commit that supplied them.

### 8.2.4 Runtime Safety Boundaries

- BNO085 or ToF initialization failure causes a software reset before a run can begin.
- A stale or out-of-range ToF value is invalidated and cannot become a wall reference.
- OpenMV packet validation requires the active packet format before vision data changes state.
- In Open mode, `FINISHED` prevents further navigation-state execution. In Obstacles mode, the finish flag commands zero motor PWM on every later loop. Physical stopping and final position are checked in the validation matrix.

---
### 8.3 Sensor Interface Contracts

Sensor drivers validate and normalize their data before the navigation state machine uses it.

| Source | Teensy interface | Packet or report | Validation | Competition firmware |
|---|---|---|---|---|
| Four VL53L8CX sensors | Direct SPI through `TOF4Walls` | Four local distance streams in millimeters | Accept non-negative readings below 3000 mm; invalidate a stream after 50 ms without fresh data | `src/lib/TOF4Walls/` |
| OpenMV N6 — Obstacles | `Serial3`, 115200 baud | 14 bytes: `AA 55`, obstacle X/Y, parking-wall X/Y and blue-line Y as five big-endian `uint16`, one flags byte, then XOR of bytes 2–12 | Require header and checksum; a valid packet becomes stale after 500 ms | `vision/vision_obstacles.py` |
| OpenMV N6 — Open | `Serial3`, 115200 baud | 3 bytes: `AA 55 ID`; ID 1 = blue, ID 2 = orange, ID 3 = no line | Require header and an ID from 1–3; this compact frame has no checksum | `vision/open_vision.py` |
| BNO085 | `Serial4`, 115200 baud | Rotation-vector heading converted to yaw | Normalize heading before calculating angular error | Teensy driver in `src/lib/IMU/` |

The N6 sends image coordinates in pixels. Camera-derived obstacle distance is therefore an image-space quantity, not a physical millimeter measurement. The N6 firmware must preserve the packet contract above when its color thresholds or white-balance settings are updated. `vision/vision_open.py` and `src/obstaculos.py` are retained as development history and are **not** the competition entry points documented in this table.

### 8.4 Current Software Architecture

```text
 OpenMV N6 ─── UART ───┐
 BNO085 ────── UART ───┤
 VL53L8CX ×4 ─ SPI ────┼──> Teensy 4.0 ──> TrajectoryController ──> Ackermann steering + motor
 Encoder ───── Quadrature┤          │
                         │          └── UART (development) ──> XIAO ESP32-C6 ──> Debug application
                         └──> Open or Obstacles state machine
```

The Teensy owns every competition-time sensing, navigation, and actuation decision. The XIAO path is diagnostic only and is disabled for official runs.

---
### 8.5 Software Module Responsibilities

| Module | Responsibility | Inputs | Outputs |
|---|---|---|---|
| Robot | Owns the Open and Obstacles state machines and selects the active navigation behavior | Validated sensor data, IMU heading, encoder distance, camera data | Steering targets, movement commands, state transitions |
| Move | Controls propulsion and converts encoder counts into distance/speed information | Encoder pulses, target speed/distance | Motor PWM, traveled distance, speed |
| TrajectoryController | Computes continuous steering corrections | Heading error, wall error, speed, obstacle geometry | Desired steering angle |
| AckermannController | Converts vehicle steering requests into calibrated servo positions | Desired steering angle | Servo command |
| TOF4Walls | Initializes, reads, filters, and normalizes the four wall sensors | VL53L8CX measurements | Front/rear/left/right distances |
| IMU | Reads and normalizes BNO085 heading | Rotation vector | Yaw and heading error |
| OpenMV program | Detects direction markers, blue lines, and obstacles | Camera image | UART packets |
| UI | Handles start button, buzzer, LEDs, and local feedback | Robot state / user input | Visual/audio feedback |

### 8.6 Control Data Flow and Loop Order

#### Control Data Flow

```text
Sensors
    ↓
Driver validation and normalization
    ↓
Robot state machine
    ↓
TrajectoryController
    ↓
AckermannController / Move
    ↓
Steering servo and drive motor
```

Sensor drivers do not make navigation decisions. The Robot state machine selects the current behavior, while the trajectory and actuator layers convert that behavior into steering and propulsion commands.

#### State Machine and Continuous Control

The state machine decides what the robot is trying to do; the continuous controllers decide how to steer while doing it. `FOLLOW_WALL` selects wall-following behavior, while Stanley continuously calculates steering. `EVADE_UNTIL_EDGE` selects obstacle-avoidance behavior, while the tangential controller continuously recalculates the steering request from the latest obstacle position.

#### Control Loop Execution Order

During a normal Obstacles iteration, the controller performs this sequence:

1. Update IMU heading.
2. Update ToF measurements.
3. Read and validate camera packets.
4. Update encoder and motion state.
5. Execute the active state-machine state.
6. Compute the steering target.
7. Apply Ackermann steering limits.
8. Apply the motor command.
9. Publish development telemetry when enabled.

The top-level Obstacles loop remains short because sensing and behavior are delegated to their corresponding modules:

```cpp
void loop() {
    robot.imu.update();
    robot.updateSensors();
    robot.updateCam();
    robot.printData();
    robot.executeTaskObstacles();
}
```

The first three updates refresh heading, wall distances, and vision. The final call executes the active state, calculates its steering request, applies the steering limit, and commands propulsion. The diagnostic output does not select or modify navigation behavior.

Open follows the same sensing-to-actuation order, but reads the compact direction-marker packet and executes the Open state machine instead of obstacle evasion.

#### State Transition Inputs

| Input | Used for |
|---|---|
| Encoder distance | Straight-segment completion, line re-arm, final travel |
| BNO085 heading | Turn completion, heading correction |
| Front ToF | Corner approach and blue-line maneuver |
| Side ToF | Wall following and emergency wall protection |
| OpenMV line detection | Direction selection and Obstacles turn trigger |
| OpenMV obstacle data | Red/green evasion and recovery |

#### Why This Software Architecture

The Teensy makes every time-critical navigation decision so the vehicle does not depend on a network or external computer. OpenMV processes images locally and sends compact detections instead of complete frames. The XIAO remains outside the control loop and is used only for optional development telemetry. Separating sensing, navigation, continuous control, and actuation keeps failures and tuning changes isolated. Open and Obstacles reuse the same hardware drivers and actuator modules while keeping their navigation behavior in separate state machines.

### 8.7 Main Control Parameters

| Parameter | Current value | Effect |
|---|---:|---|
| Stanley wall gain | `0.002` | Scales lateral correction from the selected wall-distance error |
| Stanley heading gain | `1.0` | Keeps the vehicle aligned with the active IMU heading target |
| Desired wall distance | `300 mm` | Defines the lateral clearance used by Stanley wall following |
| Maximum steering angle | `±25.94°` | Prevents requests beyond the calibrated Ackermann and servo range |
| Tangent safety radius | `120 px` | Defines the image-space clearance around a detected obstacle |
| Tangent activation distance | `170 px` | Begins blending obstacle avoidance into heading control |
| Tangent full-weight distance | `150 px` | Applies full tangential avoidance inside this image-space distance |
| Close-obstacle recovery threshold | `80 px` | Starts the timed recovery interrupt when normal evasion has insufficient clearance |
| ToF timeout | `50 ms` | Invalidates a wall-sensor stream that stops updating |
| Camera timeout | `500 ms` | Marks obstacle and line data stale when no valid packet arrives |
| Blue-line debounce time | `30 ms detection; 100 ms clear-to-rearm` | Rejects brief line detections and requires stable absence before the next trigger is armed |
| Blue-line re-arm distance | `1500 mm` | Prevents the same line or nearby image noise from triggering another turn immediately |

Competition tuning values are centralized for review in this section and can be adjusted without modifying the state-machine structure. Shared motion, tangential-evasion, recovery, and blue-line values live in `src/include/ControlValues.h`; the current wall reference and sensor timeouts are owned by `src/lib/Robot/Robot.h`, the steering limit by `src/lib/AckermannController/AckermannController.h`, and the Stanley gains by the wall-following behavior in `src/lib/Robot/Robot.cpp`.

### 8.8 Software Traceability

The architecture described in this chapter must always be associated with an exact firmware revision. A branch or pull request identifies the development path, while the commit SHA identifies the code that was actually tested.

| Reference | Purpose | Individual implementation commits | Lifecycle state |
|---|---|---|---|
| [`main` at `8de5c7b`](https://github.com/chaBotsMX/chaBots-Tuneados-WRO-Future-Engineers-2026/commit/8de5c7bc375f2857ba302f1c0525ff1ad88d9a91) | Current Open and Obstacles firmware baseline | Exact source snapshot used for the next formal validation campaign | Implementation baseline as of 2026-09-07 |
| [PR #12 — PlatformIO and movement refactor](https://github.com/chaBotsMX/chaBots-Tuneados-WRO-Future-Engineers-2026/pull/12) | Reorganized the main firmware for PlatformIO and rewrote the movement service | [`1d786a9`](https://github.com/chaBotsMX/chaBots-Tuneados-WRO-Future-Engineers-2026/commit/1d786a94cfddc96b4476ffe290e282885ecb8e80), [`330c558`](https://github.com/chaBotsMX/chaBots-Tuneados-WRO-Future-Engineers-2026/commit/330c55822a5181ea8c3ef128261535b1a6133385), [`0c278ce`](https://github.com/chaBotsMX/chaBots-Tuneados-WRO-Future-Engineers-2026/commit/0c278cea854b42a36a5c09a6b2f693104cd5bc96) | Merged on 2026-07-30 |
| [PR #13 — XIAO refactor](https://github.com/chaBotsMX/chaBots-Tuneados-WRO-Future-Engineers-2026/pull/13) | Migrated the XIAO ESP32-C6 firmware and its file structure to PlatformIO | [`b893e0f`](https://github.com/chaBotsMX/chaBots-Tuneados-WRO-Future-Engineers-2026/commit/b893e0ff19096e232ec58bb3f365b31bdd885727), [`4ca50d9`](https://github.com/chaBotsMX/chaBots-Tuneados-WRO-Future-Engineers-2026/commit/4ca50d993c8a773e5033a34089d547d8c908da3d), [`6974ea8`](https://github.com/chaBotsMX/chaBots-Tuneados-WRO-Future-Engineers-2026/commit/6974ea8afe4f93a9cdee0465558deee55fb538b7), [`0b1dec5`](https://github.com/chaBotsMX/chaBots-Tuneados-WRO-Future-Engineers-2026/commit/0b1dec5cb89f76c449b6574f2ae3c0858b145010) | Merged on 2026-08-08 |
| [PR #14 — Ackermann controller](https://github.com/chaBotsMX/chaBots-Tuneados-WRO-Future-Engineers-2026/pull/14) | Added the Ackermann steering controller and its servo interface | [`f499757`](https://github.com/chaBotsMX/chaBots-Tuneados-WRO-Future-Engineers-2026/commit/f4997579a6dee7d41c2b7bf161329bbe73b685ff), [`03b1e26`](https://github.com/chaBotsMX/chaBots-Tuneados-WRO-Future-Engineers-2026/commit/03b1e2668fa3435006bb8ed13d5827066fed71e4), [`9325693`](https://github.com/chaBotsMX/chaBots-Tuneados-WRO-Future-Engineers-2026/commit/9325693eb55d1c00de34552d704608c70179c207) | Merged on 2026-08-08 |
| [PR #17 — Both-directions state machine](https://github.com/chaBotsMX/chaBots-Tuneados-WRO-Future-Engineers-2026/pull/17) | Added clockwise and counterclockwise Open operation, named control constants, and clearer state separation | [`b926e0c`](https://github.com/chaBotsMX/chaBots-Tuneados-WRO-Future-Engineers-2026/commit/b926e0c680cd5143adbd8ff1af8b53b07b4126ad), [`471e974`](https://github.com/chaBotsMX/chaBots-Tuneados-WRO-Future-Engineers-2026/commit/471e974461f40f3d8e8abfa80d775be42ed7acc7), [`df1c767`](https://github.com/chaBotsMX/chaBots-Tuneados-WRO-Future-Engineers-2026/commit/df1c7676ed0fd0539639bb11e3306517c951a1b8), [`470c56d`](https://github.com/chaBotsMX/chaBots-Tuneados-WRO-Future-Engineers-2026/commit/470c56da9e501138d06623add52a45273175141a), [`f1a7c67`](https://github.com/chaBotsMX/chaBots-Tuneados-WRO-Future-Engineers-2026/commit/f1a7c6739b6c75b84bcdac681b2c219244c7ee5d) | Integrated into the current `main` baseline; its earlier review status is historical |

Each validation campaign identifies the Teensy firmware SHA, OpenMV N6 firmware revision, robot hardware revision, and field conditions. The XIAO revision matters only when development telemetry is used. Individual rows may share this campaign metadata; a separate video is not required for every run. The complete chronological history of changes, failures, and milestones is maintained in [Section 14](#engineering-log).

## 9. Obstacle Management 

This section documents the navigation behavior for both competition modes: the inputs that affect movement, continuous obstacle evasion, state transitions, control priority, finalization, and complete invalid-data responses.

### 9.1 Runtime Inputs and Validity Rules

| Input | Information used by obstacle logic | Validity rule |
|---|---|---|
| OpenMV N6 | Red/green color ID, obstacle image position, and blue-line observation | Complete packet with the required header and XOR checksum; stale after 500 ms |
| VL53L8CX array | Front, left, right, and rear distances in millimeters | Values at or above 3000 mm, negative readings, and streams older than 50 ms are invalid |
| BNO085 | Current yaw and error relative to the active heading target | Heading is normalized before use |
| Pololu encoder | Distance since the last state transition | Encoder distance is used to re-arm blue-line logic and complete post-turn travel |
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

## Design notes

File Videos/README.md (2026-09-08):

# Competition Videos

ChaBots Tuneados — WRO Future Engineers 2026.

| Open Challenge | Obstacles Challenge |
|:---:|:---:|
| Watch the Open Challenge (https://youtu.be/oslJ-CmbmxM) | Watch the Obstacles Challenge (https://youtu.be/23dmH0szIEk) |
| [▶ Watch Open Challenge](https://youtu.be/oslJ-CmbmxM) | [▶ Watch Obstacles Challenge](https://youtu.be/23dmH0szIEk) |

Select a preview or link to watch the corresponding run on YouTube.

[Return to the project documentation](../README.md)

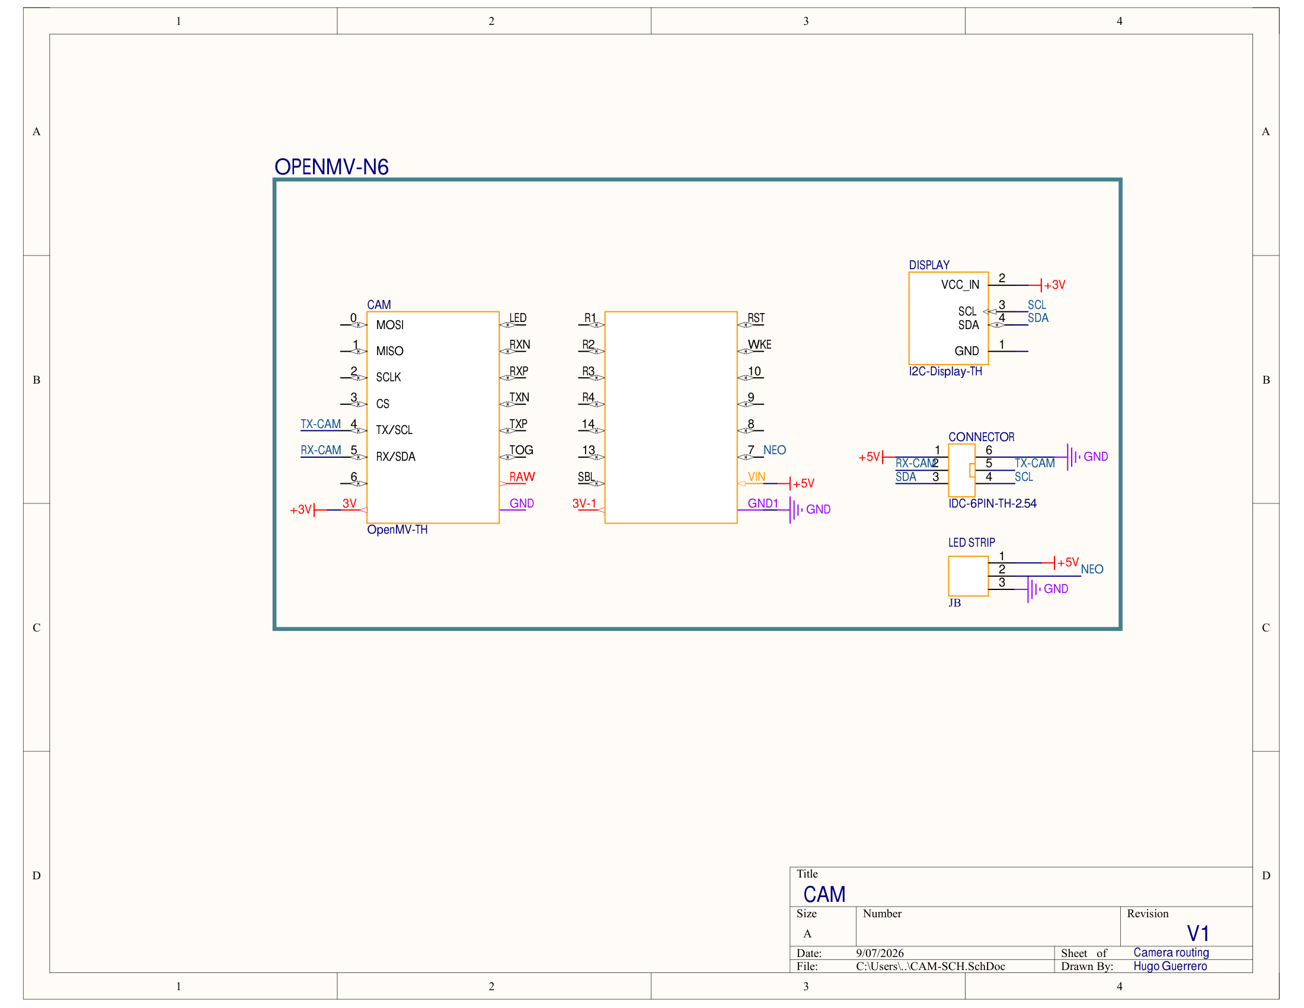
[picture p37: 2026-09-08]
Electronics/cam-pcb/CAM-SCH.png

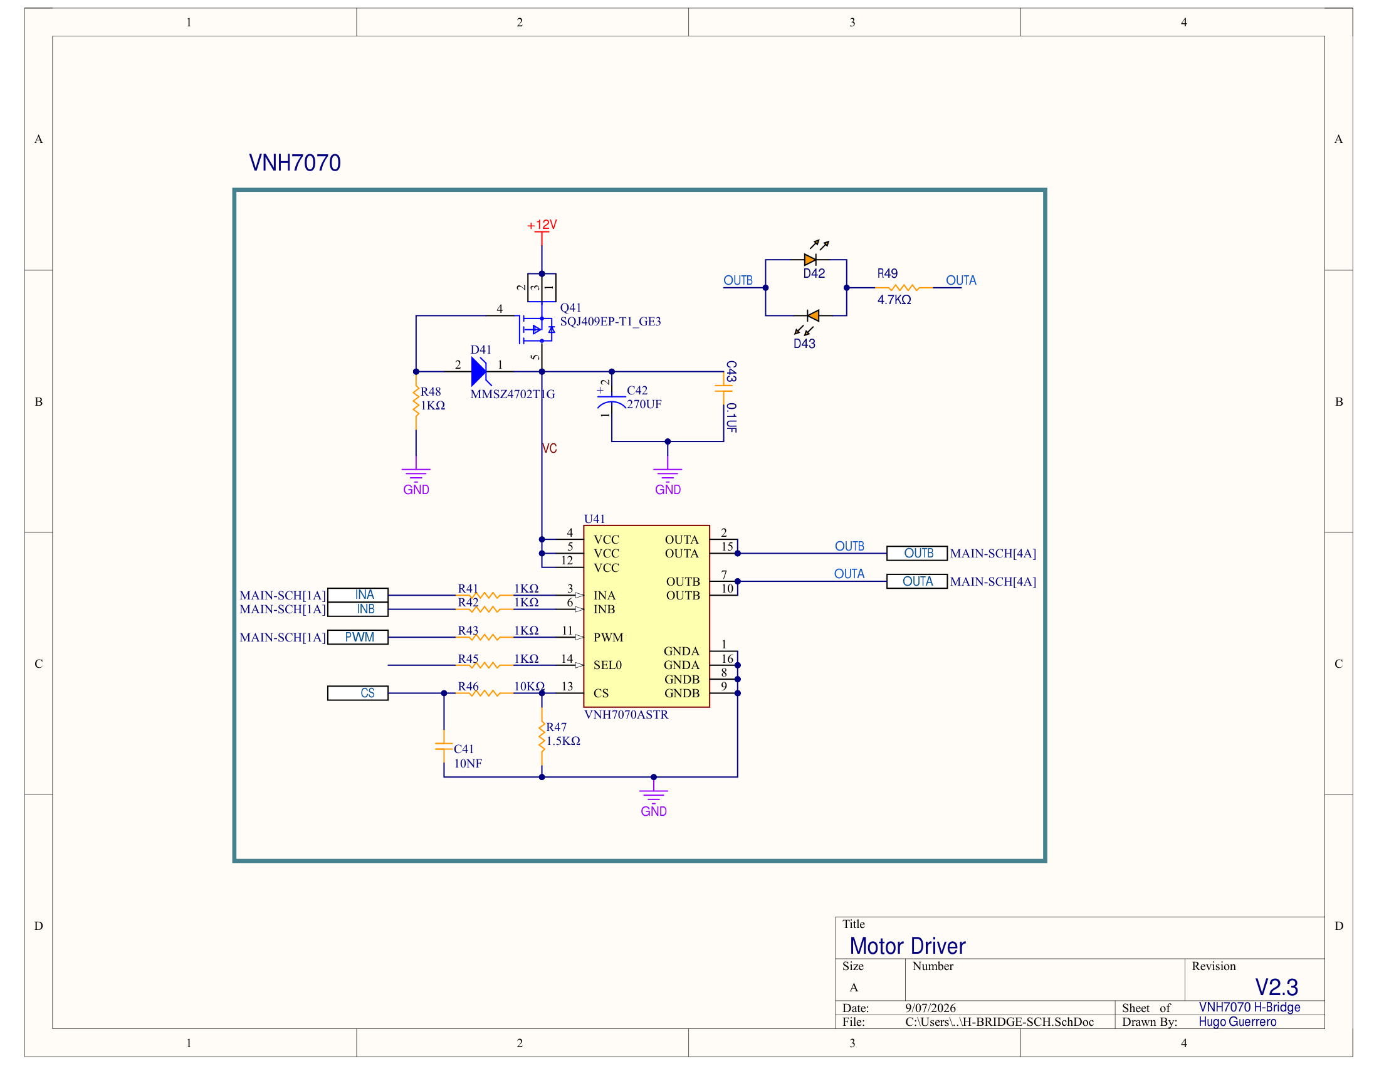
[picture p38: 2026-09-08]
Electronics/main-pcb/H-BRIDGE-SCH.png

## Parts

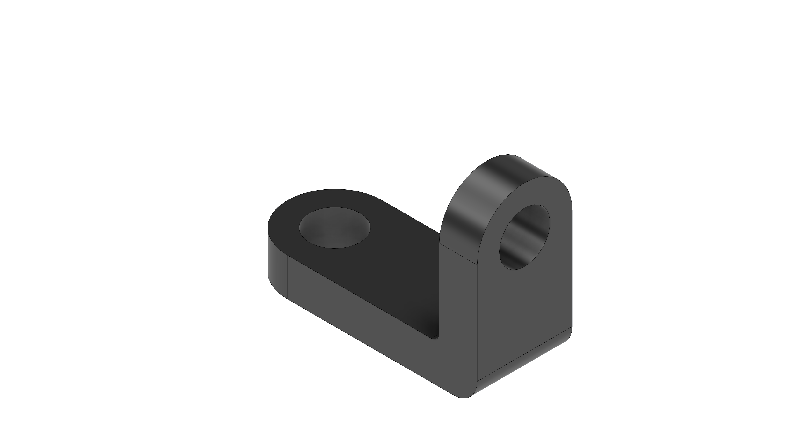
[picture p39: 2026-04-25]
models/other-components/support-tof-general.png

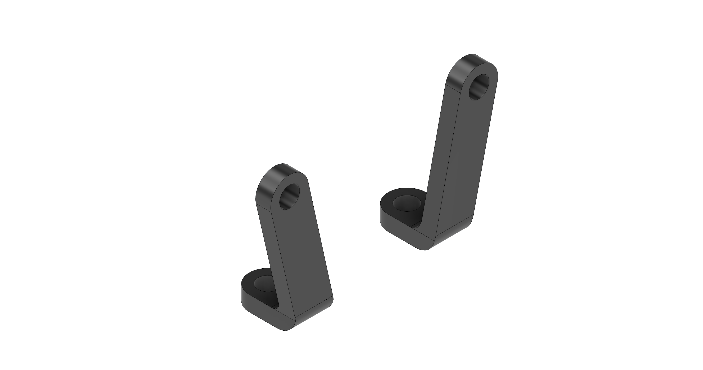
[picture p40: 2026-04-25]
models/other-components/support-tof-front.png

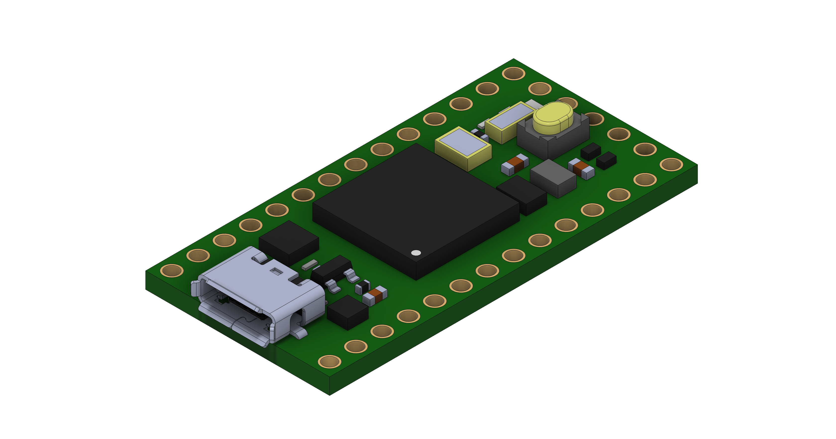
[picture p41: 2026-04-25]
models/other-components/Teensy-4.0.png

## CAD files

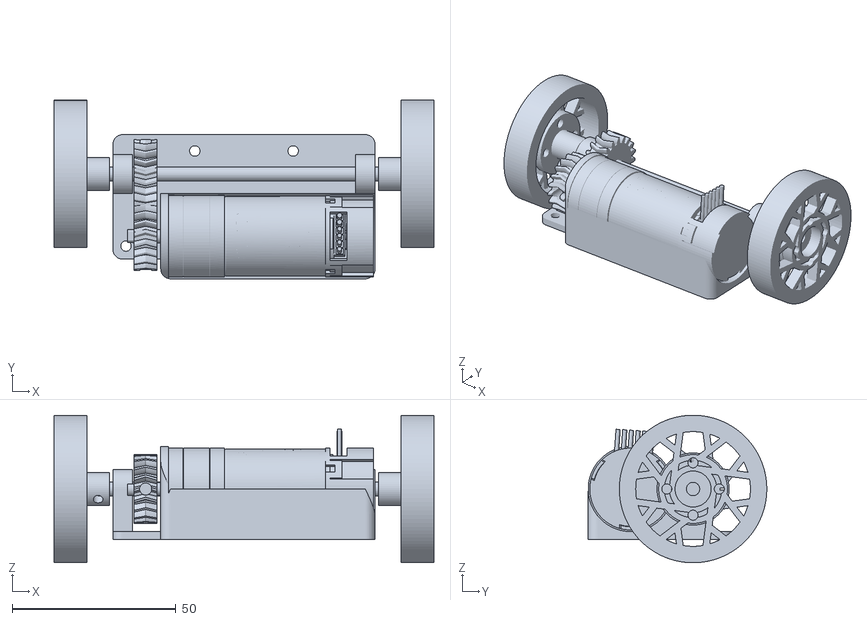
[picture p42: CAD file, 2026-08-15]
models/gearbox/gearbox-assembly.stl
115.9 x 54.5 x 45.0

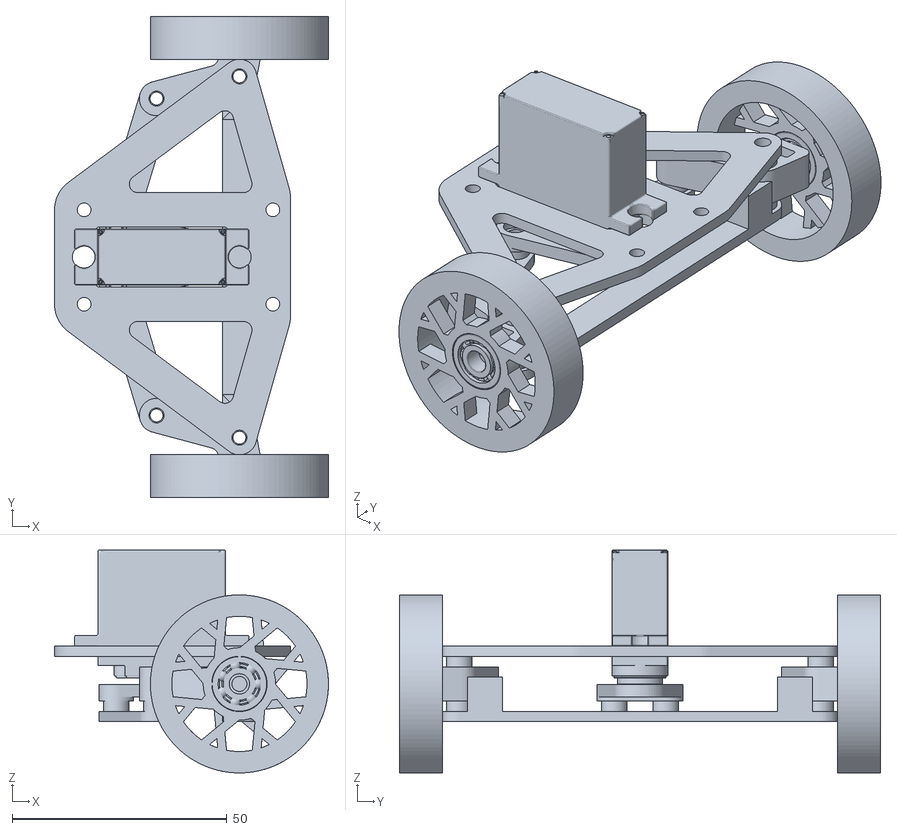
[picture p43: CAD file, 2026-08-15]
models/steering-system/steering-system-assembly.stl
63.9 x 112.2 x 51.9

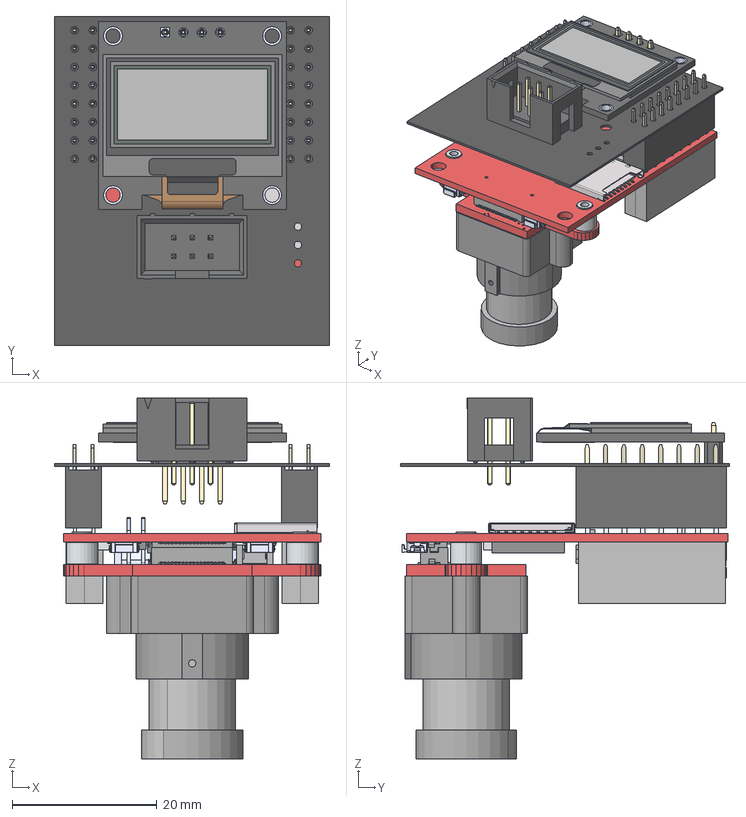
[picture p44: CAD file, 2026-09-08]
Electronics/cam-pcb/CAM-PCB.step
38.1 x 45.5 x 49.9 mm
DM-OLED096-636_Module.STEP
DM-OLED096-636_Panel.STEP
Case^IDC_По умолчанию
Pin^IDC_По умолчанию x 6
openmv-cam-rt1062
16-Pin-Header-Female-Double-2.54mm-0.step x 2

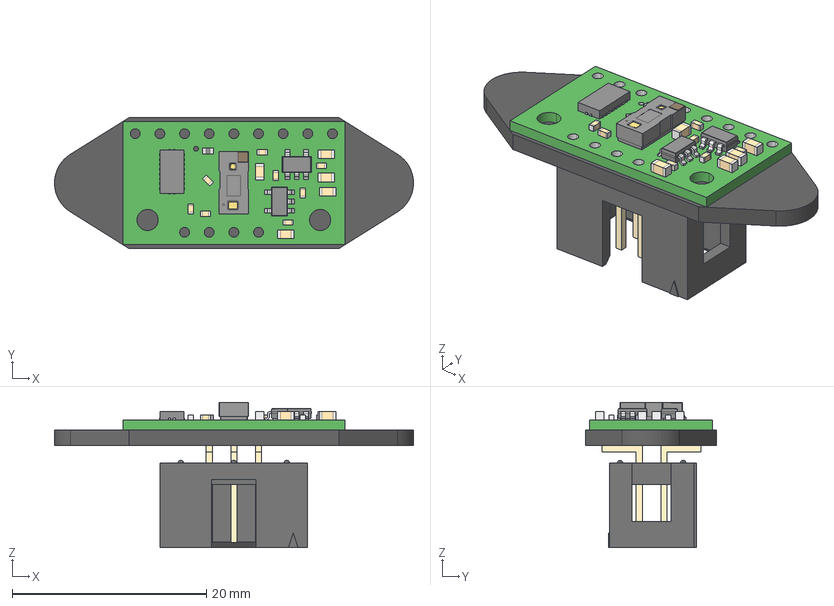
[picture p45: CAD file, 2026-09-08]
Electronics/tof-pcb/TOF-PCB.step
37.0 x 13.5 x 15.0 mm
IDC-6PIN-SMT-2.54
vl53l8cx-carrier-model

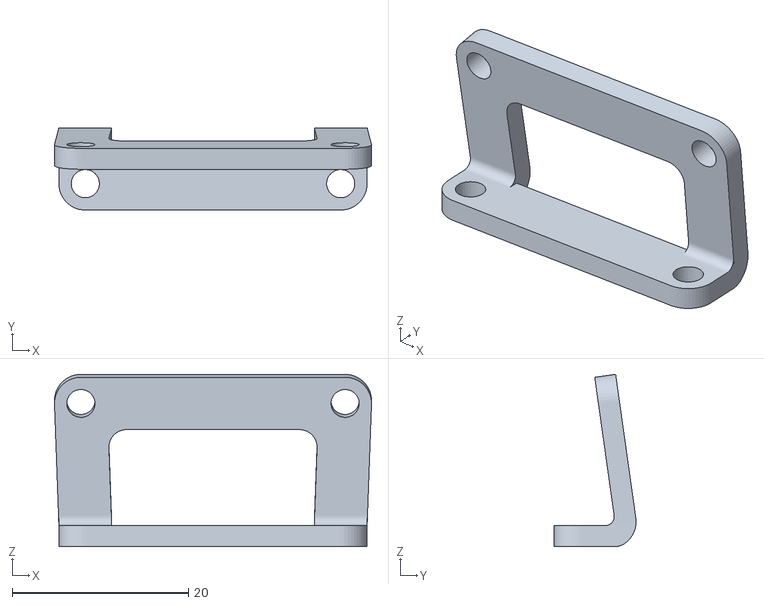
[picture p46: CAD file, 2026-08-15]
models/cam-mount/cam-support.stl
36.0 x 9.33 x 19.6

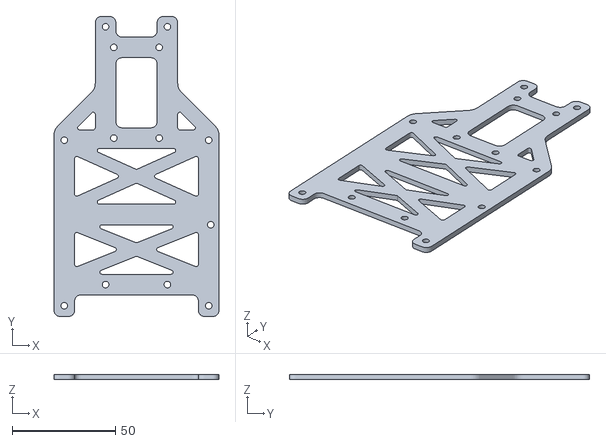
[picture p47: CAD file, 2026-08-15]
models/chassis/chassis-base.stl
80.0 x 145.5 x 2.50

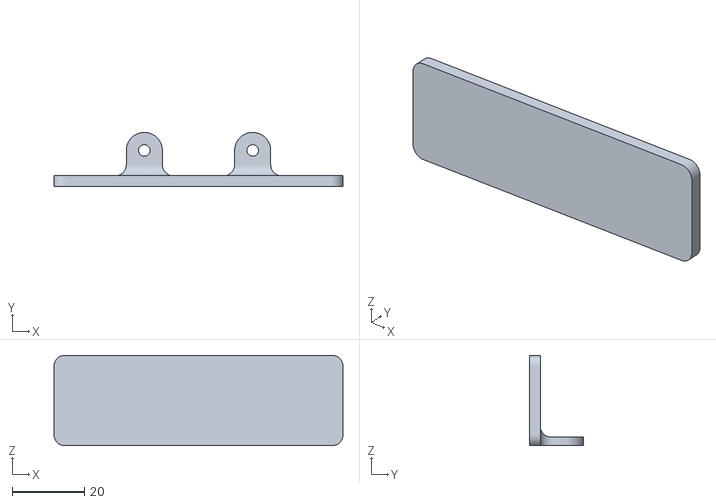
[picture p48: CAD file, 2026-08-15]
models/other-components/front-bumper.stl
80.0 x 15.0 x 25.0

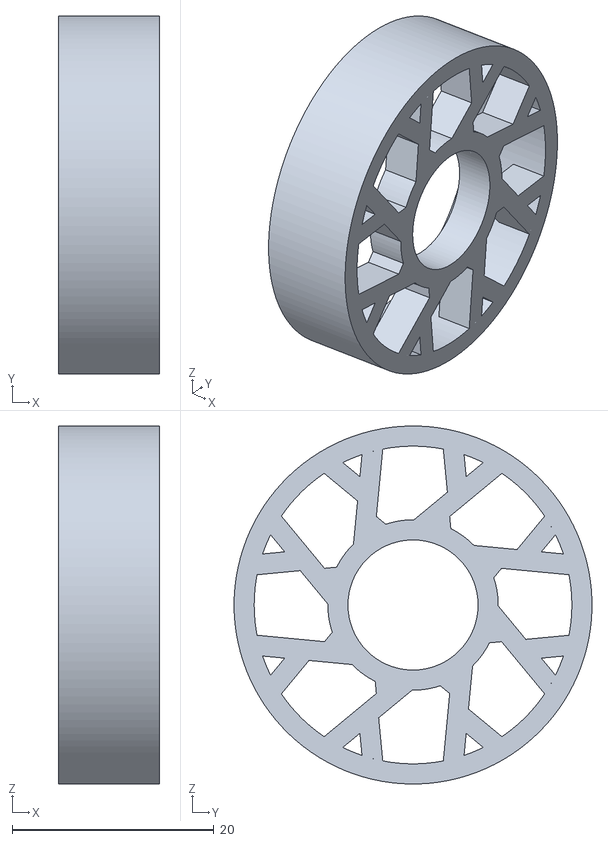
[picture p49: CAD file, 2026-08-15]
models/steering-system/steering-system-rim-s.stl
10.0 x 35.5 x 35.5

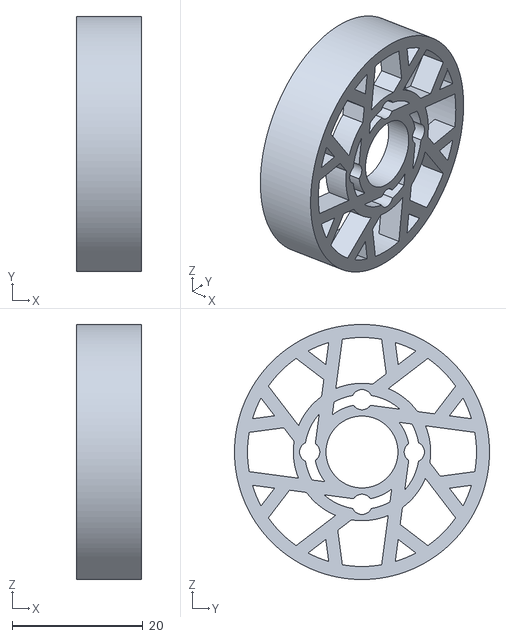
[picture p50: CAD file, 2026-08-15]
models/gearbox/gearbox-rim-g.stl
10.0 x 39.0 x 39.0

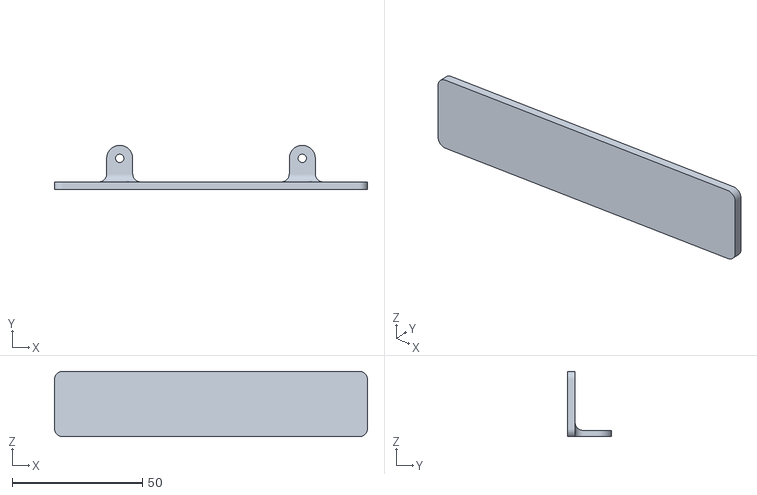
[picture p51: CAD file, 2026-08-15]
models/other-components/rear-bumper.stl
120.0 x 17.0 x 25.0

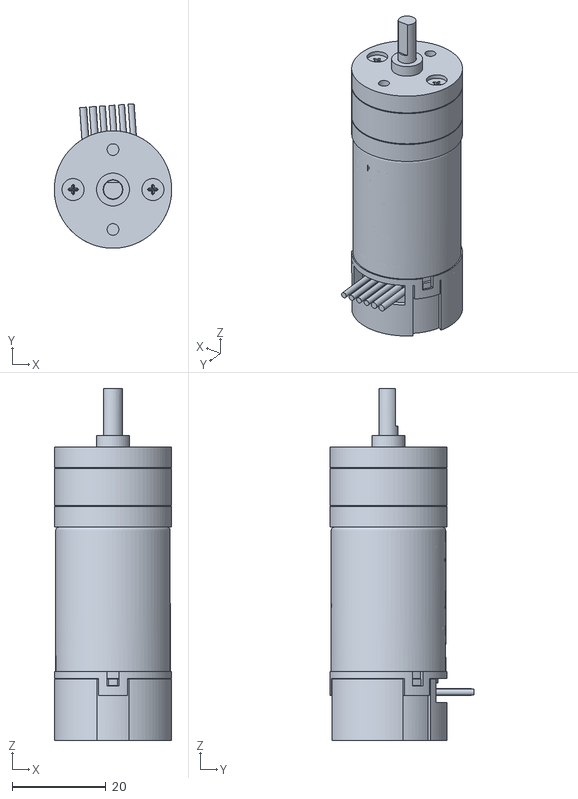
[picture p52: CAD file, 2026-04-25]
models/gearbox/gearbox-25d-metal-gearmotor-4.4-9.7-encoder.stl
25.0 x 30.7 x 75.0

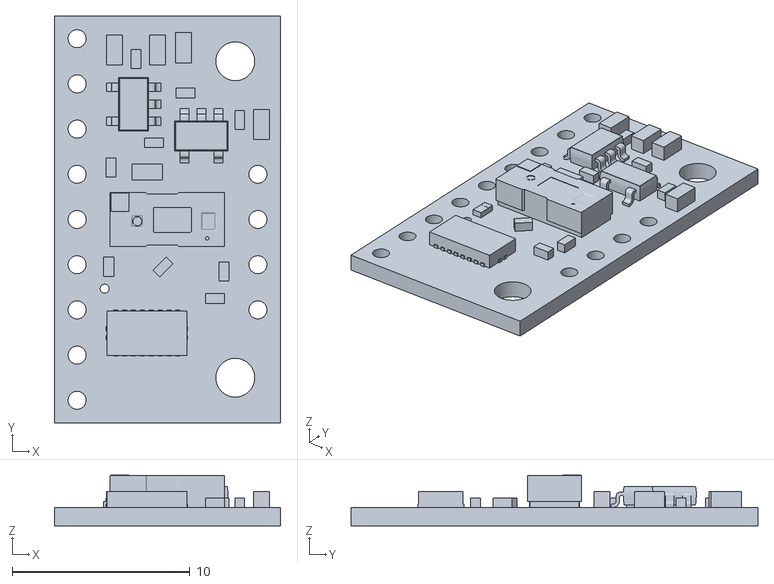
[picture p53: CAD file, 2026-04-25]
models/other-components/tof-vl53l8cx.stl
12.7 x 22.9 x 2.85

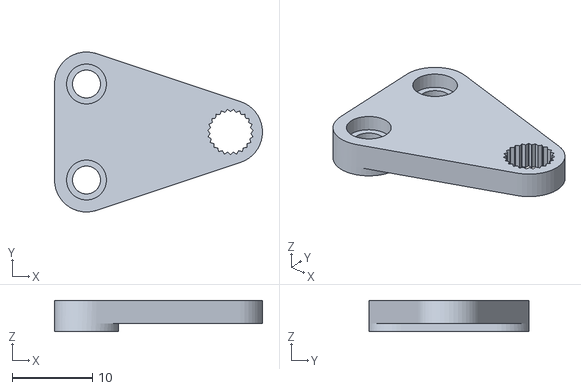
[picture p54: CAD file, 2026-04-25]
models/steering-system/steering-system-servoconnector.stl
26.0 x 20.0 x 3.90

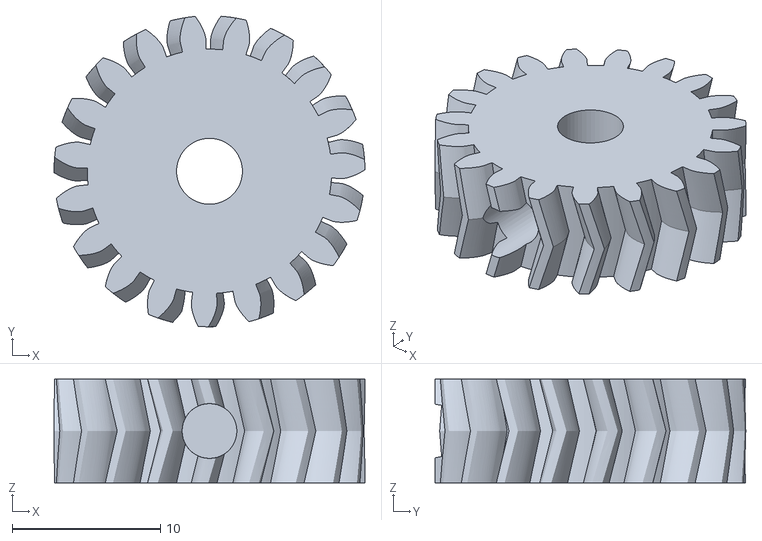
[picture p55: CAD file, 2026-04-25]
models/gearbox/gearbox-gear.stl
21.0 x 21.0 x 7.00

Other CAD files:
models/other-components/Teensy-4.0.stl
models/steering-system/steering-system-base.stl
models/gearbox/gearbox-base.stl
models/other-components/support-tof-front.stl
models/other-components/support-tof-general.stl
models/steering-system/steering-system-HS-85MG.stl
models/steering-system/steering-system-bracketconnector.stl
models/steering-system/steering-system-stabilizer.stl
models/steering-system/steering-system-wheelbracket.stl

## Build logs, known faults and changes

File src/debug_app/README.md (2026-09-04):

# Monitor de telemetría WRO

Aplicación de depuración en tiempo real para macOS. Recibe por Wi-Fi la
telemetría que el XIAO ESP32-C6 obtiene de la Teensy y presenta las lecturas y
gráficas en un dashboard local.

No instala paquetes, no necesita internet y no envía comandos de movimiento al
robot. Usa únicamente la biblioteca estándar de Python y las capacidades del
navegador.

## Inicio rápido

1. En la Mac, conéctate a la red Wi-Fi que crea el XIAO:
   `WRO-Debug-C6`.
2. Abre `start.command` con doble clic.
3. La interfaz se abrirá en `http://127.0.0.1:8765/`.
4. Para terminar, vuelve a la ventana de Terminal y presiona `Control-C`.

Si macOS no permite abrir el lanzador por primera vez, haz clic derecho sobre
`start.command`, elige **Abrir** y confirma. También se puede iniciar desde una
terminal:q

```sh
cd debug_app
python3 robot_debug.py
```

Se requiere Python 3.10 o posterior. No hay `requirements.txt` porque no hay
dependencias de `pip`.

## Probar sin hardware

El modo demostración genera todas las señales a 100 Hz y permite revisar tanto
los indicadores como las gráficas:

```sh
cd debug_app
python3 robot_debug.py --demo
```

Opciones útiles:

```text
--robot DIRECCION   IP del XIAO; predeterminada: 192.168.4.1
--udp-port PUERTO   Puerto de telemetría; predeterminado: 3333
--http-port PUERTO  Puerto de la interfaz local; predeterminado: 8765
--no-browser        No abre automáticamente el navegador
--demo              Usa datos sintéticos en lugar del XIAO
--demo-rate HZ      Frecuencia de la demostración, entre 1 y 500 Hz
```

## Qué muestra

- Velocidad en cm/s y mm/s.
- Presencia de obstáculo y vigencia de la lectura de visión.
- Número de vuelta, tarea y dirección de recorrido.
- Distancias frontal, izquierda, derecha y trasera.
- Distancia y ángulo del obstáculo.
- Ticks y distancia acumulada del encoder.
- Salidas Stanley, tangencial y comando final de dirección.
- PWM del motor y tiempo fuente de la Teensy.
- Frecuencia recibida, pérdida de paquetes, edad de la última muestra,
  secuencia, errores CRC y muestras omitidas por la transmisión de la Teensy.

Un valor inválido se muestra como `—`; nunca se confunde con cero. **Pausar
gráficas** congela solamente el historial visual: las tarjetas y el receptor UDP
continúan al día. **Limpiar** vacía el historial de las gráficas.

## Flujo de datos y latencia

La aplicación abre un socket UDP local y envía `SUB1` una vez por segundo a
`192.168.4.1:3333`. El XIAO responde con un ACK de estado y publica las tramas
al mismo puerto de origen. Al cerrar, la aplicación manda `UNS1`.

El ACK actual mide 36 bytes y usa el layout little-endian `<4sBBH7I>`: `ACK1`,
versión `1`, tamaño de telemetría `64`, tamaño de estado `36` y siete contadores
`u32`: tramas UART válidas, errores CRC UART, errores de envoltura, tramas
coalescidas, errores de envío UDP, errores de recepción UDP y errores de hardware
UART. La aplicación conserva compatibilidad con los ACK anteriores de 4 y 6
bytes, aunque esos no incluyen los contadores del puente.

El receptor guarda solamente la trama válida más reciente. El stream SSE hacia
el navegador también se limita a 50 Hz y salta estados intermedios si la interfaz
se atrasa. Así no se acumula una cola de datos viejos. Las gráficas se dibujan en
Canvas a un máximo de 25 cuadros por segundo y conservan una ventana circular de
10, 20, 30 o 60 segundos.

El servidor web escucha exclusivamente en `127.0.0.1`: otros equipos de la red
no pueden abrir el dashboard de la Mac.

## Protocolo WRO v1

Cada datagrama contiene exactamente 64 bytes en little-endian. El CRC se
transmite little-endian y se calcula con CRC-16/CCITT-FALSE, polinomio `0x1021`
e inicialización `0xFFFF`, sobre los bytes 0 a 61.

| Offset | Tamaño | Tipo | Campo |
|---:|---:|---|---|
| 0 | 4 | bytes | Magic `WRO1` |
| 4 | 1 | `u8` | Versión = 1 |
| 5 | 1 | `u8` | Tamaño = 64 |
| 6 | 2 | `u16` | Flags de validez/estado |
| 8 | 4 | `u32` | Secuencia |
| 12 | 4 | `u32` | Tiempo Teensy, µs |
| 16 | 4 | `f32` | Velocidad, mm/s |
| 20 | 1 | `u8` | Vuelta |
| 21 | 1 | `u8` | Tarea |
| 22 | 1 | `i8` | Dirección |
| 23 | 1 | `u8` | Controlador activo |
| 24 | 2 | `u16` | TOF frontal, mm |
| 26 | 2 | `u16` | TOF izquierdo, mm |
| 28 | 2 | `u16` | TOF derecho, mm |
| 30 | 2 | `u16` | TOF trasero, mm |
| 32 | 4 | `f32` | Distancia aparente al obstáculo, píxeles (hasta calibrar la cámara) |
| 36 | 4 | `f32` | Ángulo del obstáculo, grados |
| 40 | 4 | `i32` | Ticks del encoder |
| 44 | 4 | `f32` | Distancia del encoder, mm |
| 48 | 4 | `f32` | Salida Stanley, grados |
| 52 | 4 | `f32` | Salida tangencial, grados |
| 56 | 4 | `f32` | Comando final, grados |
| 60 | 2 | `i16` | PWM del motor |
| 62 | 2 | `u16` | CRC16 |

Flags:

| Bit | Significado |
|---:|---|
| 0 | Obstáculo detectado |
| 1 | Visión fresca |
| 2 | Velocidad válida |
| 3 | Encoder válido |
| 4–7 | Frontal / izquierdo / derecho / trasero válidos |
| 8 | Distancia de obstáculo válida |
| 9 | Ángulo de obstáculo válido |
| 10 | Salida Stanley válida |
| 11 | Salida tangencial válida |
| 12 | Comando de dirección válido |
| 13 | La muestra anterior no cupo en el TX UART de la Teensy y fue omitida |

Los controladores se identifican como: `0` ninguno, `1` IMU, `2` Stanley y `3`
tangencial. La dirección usa `-1` para horario, `1` para antihorario y `0` para
sin definir.

## Pruebas

Desde la raíz del proyecto:

```sh
python3 -m unittest discover -s debug_app/tests -v
```

Para una prueba funcional rápida sin abrir el navegador:

```sh
python3 debug_app/robot_debug.py --demo --no-browser
```

Abre manualmente `http://127.0.0.1:8765/` y termina con `Control-C`.

## Solución de problemas

- **XIAO conectado · esperando Teensy:** llegó el ACK del C6, pero todavía no
  ha recibido una trama UART válida desde la Teensy.
- **Buscando XIAO:** revisa que la Mac esté conectada a la red del robot y que
  el XIAO use `192.168.4.1:3333`.
- **CRC inválido:** normalmente indica ruido, pérdida de bytes o una diferencia
  entre el layout de la Teensy y el protocolo de esta aplicación.
- **TX Teensy · muestra omitida:** la muestra anterior se descartó porque no
  cabía completa en `Serial5`. Es preferible perder una muestra a frenar el lazo
  principal del robot. No indica un desborde del receptor del C6.
- **El puerto 8765 está ocupado:** inicia con otro, por ejemplo
  `python3 robot_debug.py --http-port 8766`.

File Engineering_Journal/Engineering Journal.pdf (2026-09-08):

# ChaBots - WRO Future Engineers 2026

This journal contains the documentation for ChaBots participation in the WRO Future Engineers 2026 category. Our robot was designed and built by a team of Mexican students passionate about robotics and education.

## Competition Videos

Watch Pistonudo complete the Open and Obstacles challenges. Select a preview to open the corresponding video on YouTube.

Open Challenge | Obstacles Challenge

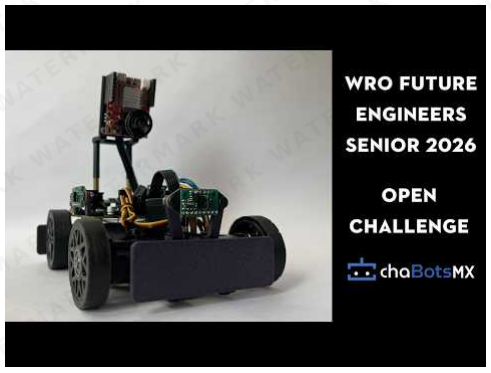
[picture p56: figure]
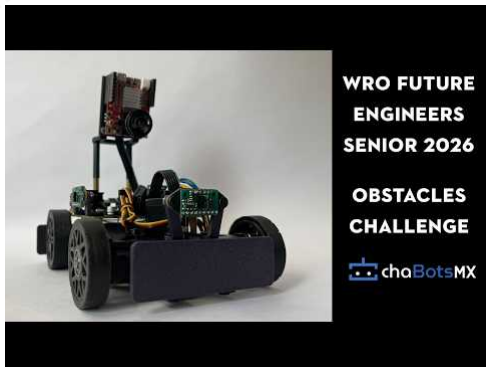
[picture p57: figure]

- Watch Open Challenge (https://youtu.be/oslJ-CmbmxM) | ▶ Watch Obstacles Challenge (https://youtu.be/23dmH0szIEk)

## 📜 Table of Contents

🎬 Competition Videos

1. 🧑‍💻 The Team
2. 🎯 The Challenge
3. 🏆 Lessons from the Previous Season
4. 🔬 Research, Development and Decision Log
5. 🤖 Final Robot Architecture
6. ⚙️ Mobility Management
7. 💡 Power, Electronics and Sensor Management
8. 💻 Software Architecture and Control
9. 🚧 Obstacle Management
10. 🧪 Testing, Validation and Results
11. ️ Construction, Serviceability and Debugging
12. 💰 Cost Report
13. 📚 Resources
14. 📋 Engineering Development Log
15. ©️ License

## 1. The Team

# WAT

## K WATERMAR ARK WATERMARK WAT RMARK WATERMARK WATERMA

## ATERMARK (https://youtu.be/oslJ-CmbmxM) WATERMARK WATERMARK WA

## K WATERMARK (https://youtu.be/oslJ-CmbmxM) WATERMARK WATERMARK WATERMA

## ARK WATERMARK WATERMARK (https://youtu.be/oslJ-CmbmxM) WATERMARK WATERMARK WA

## RMARK WATERMARK WATERMARK (https://youtu.be/oslJ-CmbmxM) WATERMARK WATERMARK WATERMA TERMARK WATERMARK WATERMARK WATERMARK (https://youtu.be/oslJ-CmbmxM) WATERMARK WATERMARK

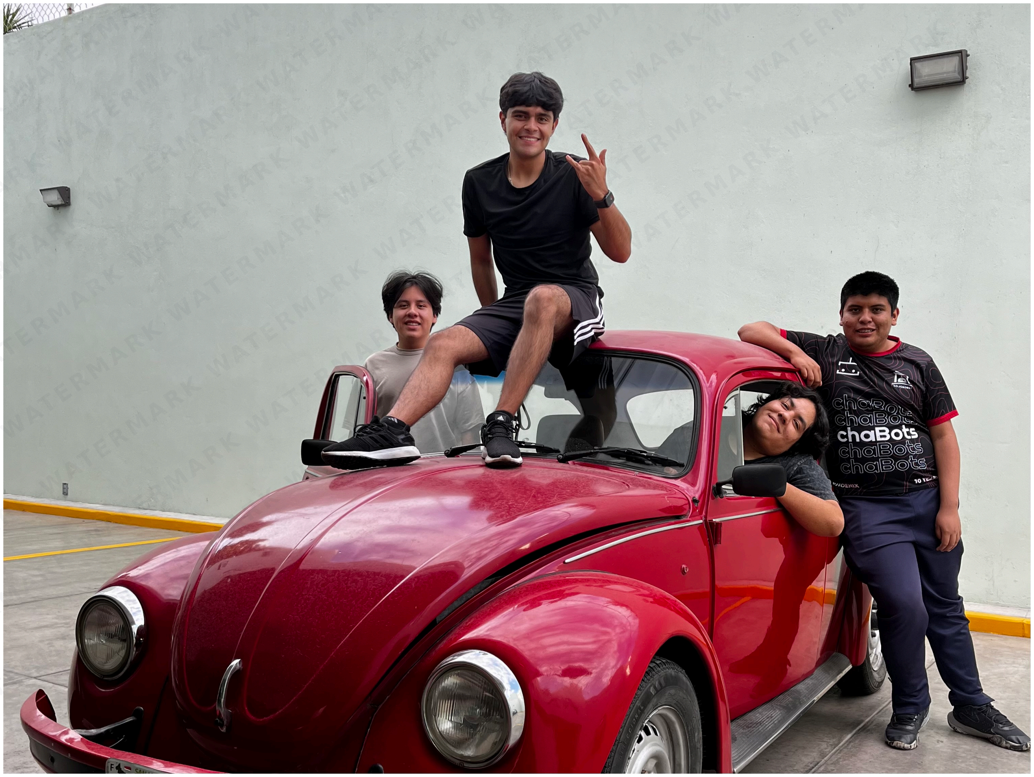
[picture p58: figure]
K WATERMAR ARK WATERMARK WAT RMARK WATERMARK WATERMA; ATERMARK WATERMARK WATERMARK WA; K WATERMARK WATERMARK WATERMARK WATERMA

We are ChaBots Tuneados -[:]

### Roy Iván Barrón Martínez

Age: 21

Role: Captain & Software Designer

I am a self-taught robotics enthusiast with experience in embedded systems, software, and mechanical integration. my team ChaBots Ocelot won Mexico Robocup soccer Open second place and achieved multiple national awards in programming and robotics.

"I enjoy setting nearly impossible goals to push myself while learning. I believe that learning should always lead to building something real."

### Leonardo Villegas López

Age: 21

Role: Mechanical Designer

I am a Mechatronics Engineering student passionate about technology and innovation. I have been a contestant for eight years, winning various regional and national competitions, and participating internationally.

"I will take any opportunity to grow"

### Hugo Iván Guerrero Díaz

Age: 19

Role: Electronics Designer

## ARK WATERMARK WATERMARK WATERMARK WATERMARK WA

## RMARK WATERMARK WATERMARK WATERMARK WATERMARK WATERMA TERMARK WATERMARK WATERMARK WATERMARK WATERMARK WATERMARK

I am a Mechanical Engineering student that has been participating in robotics competitions since 2019. I won at the RoboCup Mexican Open and represented Mexico at the international RoboCup event in Brazil.

"I miss her."

### Diego Vitales Medellín

Age: 23

Role: Coach

I've been involved in robotics for more than 14 years, working as a programmer on most of the projects in which I have participated. I have had many regional, national, and international experiences. I now share that knowledge to help others develop their skills, reach their goals, and find their passion.

"I like to face challenges and even more so when it's with more people. Learning and creating something is better when shared."

## 2. The Challenge

The WRO Future Engineers challenge pushes students to create fully autonomous self-driving vehicles. Each robot must:

Navigate a dynamically randomized track

Detect and avoid colored obstacles (green/red blocks)

Execute a parallel parking maneuver

Scoring is based on:

Performance on track

Obstacle handling

Documentation quality

Innovation and engineering rigor

For more information, visit the WRO official website. (https://wro-association.org/)

## 3. Lessons from the Previous Season

### 3.1 What Happened

Last year was an incredible experience. We were able to achieve first place nationally and later reached 36th place at the international competition. Beyond the results, we identified several important issues in our robot. We also took notes on what we observed and discussed with other teams, which gave us valuable information to improve almost every aspect of our design.

### 3.2 Design Philosophy

Our design philosophy has not changed much from last year. Instead, we found better ways to accomplish what we had originally planned.

Historically, in this and other competitions, we have preferred to build a new robot from scratch every year. We believe this is one of the best ways to push ourselves to improve, learn from previous mistakes, and avoid repeating old limitations. Because of that, this remains one of our core design principles.

Our main design goals are:

Small size

Reliability

Avoiding unnecessary overengineering

Consistency

## K WATERMAR ARK WATERMARK WAT RMARK WATERMARK WATERMA

## ATERMARK WATERMARK WATERMARK WA

## K WATERMARK WATERMARK WATERMARK WATERMA

## ARK WATERMARK WATERMARK WATERMARK WATERMARK WA

## RMARK WATERMARK WATERMARK WATERMARK WATERMARK WATERMA TERMARK WATERMARK WATERMARK WATERMARK WATERMARK WATERMARK

### 3.3 What Went Wrong

Our robot had three main issues, which affected us mostly during the obstacle round:

Poor steering design

Poor camera software and camera ecosystem

Poor low-speed movement control

Our steering design was good enough for the open round. In fact, we were able to complete some runs in only 22 seconds. However, it performed very poorly in the obstacle round because the robot was not able to take tight turns. This was mainly caused by the mechanical design of the steering system. We will explain this in more detail later.

The camera software itself was not necessarily terrible, but the entire camera ecosystem was problematic. Last year, we decided to use ROS2, which turned out to be a bad choice for our specific needs. Using ROS2 usually means working with Ubuntu or another Linux distribution instead of simply using Raspberry Pi OS. Although ROS2 can be used on Raspberry Pi OS, it is generally easier to use it with Ubuntu.

This decision caused several problems. Our camera required unusual drivers that were not official and had almost no documentation. As a result, we had trouble disabling white balance and automatic brightness. We also experienced significant camera delay, processing delay, and inconsistent image behavior.

The movement system was good, but it was not optimal for the obstacle round. We needed precision, but our motors were focused more on speed. Since our motors did not have encoders, we could not control low-speed movement accurately. Even though the motors had good torque, it was not enough to move smoothly at low speeds. This was one of the reasons why we were unable to leave the parking lot last year.

## 4. Research, Development and Decision Log

This year, we spent a lot of time on research and development to solve the issues mentioned above and improve our overall performance.

This section will be quite large because we want to include everything we found important and useful, not only for us, but also for other teams.

We decided to go back to the basics and review everything we might have missed last year.

### 4.1 Mobility

The first thing that comes to mind when talking about mobility is motors. Motors are one of the most important parts of any robot. However, we found that even a good motor is not enough without a good steering system.

Still, let us start by talking about the motors.

### 4.1.1 Which Motor Should We Use?

First, we need to understand what makes one motor different from another.

The most important characteristics are:

Speed, measured in RPM

Torque, usually measured in kg·cm or N·m

Current consumption, measured in amps

Weight, measured in grams

Price

The first thing most people consider when choosing a motor is speed. However, speed cannot be analyzed alone. In electric motors, speed is directly related to torque. In general, the more torque a motor has, the less speed it will have. Likewise, the more speed it has, the less torque it will provide.

This relationship is known as the torque-speed curve, and it is present in every motor. If we want more torque, we usually have to sacrifice speed.

The only way to reduce this limitation is to buy a better motor or use a more powerful one. However, using a more powerful motor usually means higher current consumption.

## K WATERMAR ARK WATERMARK WAT RMARK WATERMARK WATERMA

## ATERMARK WATERMARK WATERMARK WA

## K WATERMARK WATERMARK WATERMARK WATERMA

## ARK WATERMARK WATERMARK WATERMARK WATERMARK WA

## RMARK WATERMARK WATERMARK WATERMARK WATERMARK WATERMA TERMARK WATERMARK WATERMARK WATERMARK WATERMARK WATERMARK

The following table compares some motors we considered. We usually prefer motors from known brands because generic motors often have poor quality and unrealistic specifications.

Model | Speed (RPM) | Torque (kg/cm) | Current (A) | Weight (g) | Voltage | Price (USD)
Maxon DCX19 | 600 | 6.5 | 2.0 | 80 | 12V | 500
Pololu 25D HP 20.4:1 | 480 | 4.8 | 6.0 | 107 | 6V | 37.95
Pololu 25D LP 9.7:1 | 630 | 1.3 | 2.0 | 100 | 6V | 33.00
Generic (Pololu 25D copy) | 620 | 0.22 | not specified | 120 | 12V | 10.00
Lego EV3 (EV3 Medium Motor, 45503) | 240-260 (no-load) | ~2.2 kg·cm stalled | no-load ~0.10 A, stall ~0.62 A | 42 g | ~9V (powered by EV3) | low ($)
Pololu 25D HP 20.4:1 (with encoder) | 500 | 7 kg·cm stalled | no-load 0.30 A, stall 5.00 A | 120 g | 12V | 56.95

Before choosing a motor, we need to understand what we need from it. In this case, a robot built for Future Engineers must weigh a maximum of 1.5 kg. Torque is not only important for making the robot move. It also affects:

The ability to accelerate quickly

The ability to climb small inclines

The ability to overcome small obstacles

The ability to maintain speed under load

The ability to stop quickly

The ability to reverse quickly and change direction

So, how much torque do we need?

This is a complex question because it depends on many factors, such as the weight of the robot, wheel friction, track surface, and target speed. However, we can use our experience as a starting point.

In our case, we know from experience that we need at least twice the robot’s weight in torque. If our robot weighs 1.5 kg, we need at least 3 kg·cm of torque. This is only a starting point, but it is a useful reference.

Regarding RPM, we know that we do not need extremely high speed because the track is small and the robot must be able to stop quickly. For this reason, we can sacrifice some speed in exchange for more torque. A target speed of around 350 to 400 RPM is usually enough.

However, this target refers to the actual speed at which we want the motor to run, not necessarily the motor’s rated RPM. It is not ideal to run a motor at its maximum rated speed all the time because torque will be lower and current consumption will be higher. Instead, it is better to choose a motor with a higher rated speed and operate it below its maximum.

For example, if we need around 400 RPM, we can choose a motor rated for 500 to 700 RPM. This allows us to run the motor at a lower percentage of its rated speed, which gives us better torque and lower current consumption. As a reference, good-quality motors can usually run at 70% or 80% of their rated RPM without problems. A 600 RPM motor, for example, can be used around 420 RPM reliably.

Now that we know the approximate torque and speed we need, we can talk about power consumption.

Choosing between a 6 V motor and a 12 V motor mainly depends on the battery we plan to use. If we use a 6 V battery, we should choose a 6 V motor. If we use a 12 V battery, we should choose a 12 V motor.

However, in practice, it is not always that simple. LiPo batteries do not provide a constant voltage. For example, a 2S LiPo battery has a nominal voltage of 7.4 V, but it can be fully charged at 8.4 V and drop close to 6 V when it is almost empty.

This is usually not a serious problem because most motors can handle a small amount of overvoltage. Undervoltage is also not dangerous for a DC motor; the motor will simply run slower or may not move if the voltage is too low.

The real issue is that torque and RPM are directly related to voltage. If the battery voltage drops, the robot may lose torque and speed. This is something to consider when diagnosing movement problems. Sometimes the robot may not move correctly simply because the battery is almost empty.

## K WATERMAR ARK WATERMARK WAT RMARK WATERMARK WATERMA

## ATERMARK WATERMARK WATERMARK WA

## K WATERMARK WATERMARK WATERMARK WATERMA

## ARK WATERMARK WATERMARK WATERMARK WATERMARK WA

## RMARK WATERMARK WATERMARK WATERMARK WATERMARK WATERMA TERMARK WATERMARK WATERMARK WATERMARK WATERMARK WATERMARK

One possible solution is to measure the battery voltage and compensate for it in software to keep the speed more constant. This is not strictly necessary, but it can help a lot.

There are two common types of motors we can use: simple DC motors and DC motors with encoders. In many cases, they are the same motors, but with an encoder added. Encoders are important when precision and control are needed.

Last year, we completed the challenge without encoders, but we found that having full control over motor speed would allow us to implement features that could help in specific situations, such as leaving the parking lot. We are also preparing for possible new mystery rules this year, so having better control gives us more flexibility.

Finally, we need to talk about price. Good-quality motors are expensive, but they are usually worth it because they last longer, perform better, and are more reliable. If you can afford them, it is usually a good investment. However, if you cannot, there are still good options available. Pololu motors, for example, are good enough for many hobby and competition applications.

There are much better motors, such as Maxon motors, which are used in industrial and even aerospace applications. However, for many robotics competitions, Pololu motors offer a good balance between price, quality, and performance.

It is also important to mention that motor requirements can be calculated. There are many online calculators that can help estimate torque and speed requirements. However, the most important thing is to test the motor under real conditions because theoretical calculations are not always accurate.

After considering all of this, we chose the Pololu 25D Metal Gearmotor 20.4:1 HP 12 V with 48 CPR Encoder, product #3203. Its documented no-load output speed is approximately 500 RPM at 12 V. This exact designation is used throughout the current-robot sections of this README.

Last year, we used the Maxon DCX19, and it worked very well for speed. We were able to complete the open round in less than 20 seconds. Our fastest run was 18 seconds. Even in the tightest case, where all four inner walls were present and there was only around 40 cm of space for the robot to drive, we were able to complete the round in 35 seconds.

However, we had many issues in the obstacle round because we did not have good control at low speeds. This is the main reason why we chose motors with encoders this year instead of using the Maxon motors again.

The Maxon motors are linear, smooth, and easy to predict. However, with encoders, we can achieve accurate movement through feedback control instead of relying only on the quality and natural behavior of the motor. This also gives us the possibility to move at lower speeds with much better accuracy.

### 4.1.2 Which Motor Should We Use? Servo Edition

Why to use a servo?

We need a simple and reliable steering system, and a servo is perfect for this. We do not need extremely high speed or extreme torque. We only need to turn the wheels accurately and consistently.

Most teams already know this, but we want to share our experience. This section will be shorter because choosing a servo is not as complex as choosing a drive motor.

Here are some servo options:

Model | Torque (kg/cm) | Current (A) | Size | Weight (g) | Quality | Price (USD)
HS 85MG | 3 | 1.2 | Small | 21 | Excellent | 40.00
MG996 | 13 | 1.2 | Really big | 66 | Bad | 10.00
MG95 | 1.8 | 1.0 | Small | 9 | Bad | 2.00

This is only a comparison between the servo we chose and some generic options. There are many good servo brands, but comparing all of them would make this section too long.

We chose the HS-85MG because it is a high-quality servo with metal gears, good torque, and a compact size.

The most important factor when choosing a servo is torque. The servo must have enough torque to turn the wheels. If there is too much weight over the steering system, the servo may struggle to move the wheels. Because of this, we need a servo with enough torque for the mechanical load.

It is easy to find servos with a lot of torque, but they are usually large. This may not be a problem for every team, but it is a problem for us because we want to keep the robot as low as possible. That is why we chose this servo: it is small, has good torque, and works reliably.

## K WATERMAR ARK WATERMARK WAT RMARK WATERMARK WATERMA

## ATERMARK WATERMARK WATERMARK WA

## K WATERMARK WATERMARK WATERMARK WATERMA

## ARK WATERMARK WATERMARK WATERMARK WATERMARK WA

## RMARK WATERMARK WATERMARK WATERMARK WATERMARK WATERMA TERMARK WATERMARK WATERMARK WATERMARK WATERMARK WATERMARK

The HS-85MG provides around 3.0 kg·cm of torque at 5 V. It is expensive, but in our case, it was worth it. If you need a more affordable option, you can use a generic servo, but make sure to test it carefully before using it in a real competition robot.

### 4.1.3 What Makes a Servo Good Quality?

It is easier to understand servo quality by looking at the problems that low-quality servos can have. The first issue is that the specifications are often inaccurate or exaggerated. However, that is only the beginning.

Bad-quality servos can have problems such as:

Poor control

Imprecise movement

High backlash

Short lifespan

Inconsistent behavior under load

Servos are usually easier to choose than drive motors. Good servos are common, and even some generic servos can work well. However, there are also many low-quality clones, so it is important to test them before using them in an important project.

### 4.2 Integrating Both Motors into a Steering System

After selecting the drive motor and steering servo, the next step was to integrate them into one mechanically consistent mobility system. This was one of the most important design decisions because motor performance alone does not determine how accurately the robot moves. The geometry, transmission, wheel alignment, structural stiffness, tire behavior, and weight distribution all affect the final trajectory.

Regulatory constraints

The 2026 Future Engineers rules require a four-wheeled vehicle with one driving axle and one steering actuator. Front-wheel drive, rear-wheel drive, and four-wheel drive are permitted, but a differential-wheeled robot and an electronic differential with independently driven left and right sides are not allowed.

The rules also permit a maximum of two driving motors, but they must be mechanically connected to the driving axle and cannot independently control the left and right wheels. Therefore, our drivetrain had to behave as one mechanically coupled drive system rather than steering by changing the speed of each side.

This requirement creates a different design problem from a differential-drive robot. Direction changes must be produced by steering geometry, while the coupled driving wheels continue receiving the same mechanical input.

Designing a competition robot rather than a scaled car

Last year, we approached the vehicle as if we were building a small conventional car. This provided a useful starting point, but this year we recognized that the objective is not to reproduce a road vehicle visually. The objective is to engineer the most effective robot for the dimensions, speeds, materials, rules, and field conditions of this challenge.

Full-size automotive principles such as Ackermann steering, controlled weight distribution, rigid wheel alignment, and low mechanical play remain useful. However, their implementation must be adapted to a lightweight robot made with small servos, printed components, compact bearings, and tires that deform differently from full-size vehicle tires.

For this reason, the new robot does not attempt to look like a Formula 1 car or reproduce a real vehicle at scale. Its geometry was designed around the competition task, available manufacturing methods, required turning radius, sensor placement, and serviceability.

Main mechanical challenges

Problem | Principal causes | Effect on the robot | Design response
Backlash and compliance | Clearance between gear teeth, servo gearbox play, loose joints, output-spline movement, flexible printed parts, and bearing clearance | Delayed steering response, oscillation, inconsistent straight-line position, and different behavior when changing direction | Better servo, rigid supports, short linkages, controlled gear center distance, reduced joint clearance, and calibration from both steering directions

## K WATERMAR ARK WATERMARK WAT RMARK WATERMARK WATERMA

## ATERMARK WATERMARK WATERMARK WA

## K WATERMARK WATERMARK WATERMARK WATERMA

## ARK WATERMARK WATERMARK WATERMARK WATERMARK WA

## RMARK WATERMARK WATERMARK WATERMARK WATERMARK WATERMA TERMARK WATERMARK WATERMARK WATERMARK WATERMARK WATERMARK

Problem | Principal causes | Effect on the robot | Design response
Front-wheel scrub | Both front wheels using the same steering angle instead of following their individual turning circles | Tires fight each other, steering load increases, speed decreases, and the robot follows a larger or inconsistent turn | Ackermann steering geometry with a greater angle on the inside wheel
Driven-axle scrub | Mechanically coupled left and right drive wheels rotate together even though the outside wheel travels farther during a turn | One or both rear tires must slip, especially during tight or high-speed turns | Appropriate wheelbase and track width, compliant tires, controlled cornering speed, good alignment, and predictable weight distribution
Loss of tire contact | Twisted chassis, unequal wheel height, poor assembly tolerances, or an unsuitable center of mass | Encoder distance no longer matches robot movement and the vehicle can pull toward one side | Rigid chassis, coplanar axle installation, low center of mass, and verification that all four wheels remain loaded
Insufficient steering range | Linkage collision, limited servo travel, unsuitable servo-horn length, or wheel interference with the chassis | Large minimum turning radius and difficulty leaving or entering the parking area | CAD interference checks, mechanical steering stops, optimized linkage leverage, and maximum safe inner-wheel angle
Excessive grip or insufficient grip | Tire compound, surface material, axle load, and speed | Too little grip causes uncontrolled sliding; excessive lateral grip increases scrub in the coupled axle | Tire testing on the competition surface and speed-dependent steering control

Backlash

Backlash is the lost motion that appears when the direction of a mechanism reverses before the output begins moving. In our robot it can originate in several places:

Clearance between the transmission gear teeth.
Internal play in the servo gearbox.
Clearance between the servo spline and horn. Loose steering-link joints or fasteners.
Flexible printed brackets and shafts.
Bearing or axle play.

Backlash is not caused by the gear teeth returning to a relaxed position. It is mainly produced by clearance and elastic deformation within the transmission. Increasing the number of teeth does not automatically solve it.

Our drivetrain uses double-helical, or herringbone-style, gears. Their gradual tooth engagement and higher contact ratio can produce smoother transmission, while the opposing helix directions balance axial forces. However, this geometry does not eliminate backlash by itself. Tooth profile, printing accuracy, shaft alignment, bearing support, and gear center distance still determine the remaining play.

The steering actuator can introduce even more lost motion than the printed transmission. This was one reason for choosing the higher-quality HS-85MG servo discussed in Section 4.1.2. We also reduced linkage length and unnecessary joints so that servo movement reaches the wheels with less deformation.

Tire slip and Ackermann geometry

During a turn, every wheel follows a circle with a different radius around one instantaneous center of rotation. The inside front wheel must therefore turn farther than the outside front wheel. If both front wheels remain parallel, at least one tire must slide laterally.

Ackermann steering approximates the required relationship by arranging the steering arms and tie rods so that the projected wheel axes intersect near the rear axle. For wheelbase (L), front track width (T), and turn radius (R) measured to the vehicle centerline:

### tan(δinside) =

R − T/2

L

tan(δoutside) =
R + T/2

L

## K WATERMAR ARK WATERMARK WAT RMARK WATERMARK WATERMA

## ATERMARK WATERMARK WATERMARK WA

## K WATERMARK WATERMARK WATERMARK WATERMA

## ARK WATERMARK WATERMARK WATERMARK WATERMARK WA

## RMARK WATERMARK WATERMARK WATERMARK WATERMARK WATERMA TERMARK WATERMARK WATERMARK WATERMARK WATERMARK WATERMARK

Therefore, the inside steering angle must always be greater than the outside angle.

Ackermann geometry reduces front-wheel scrub, but it cannot completely eliminate slip in our driven axle. Because the two driving wheels are mechanically coupled, they tend to rotate through the same angle even though the outside wheel must travel farther. This is an unavoidable compromise of a locked or non-differential axle. Our objective was therefore to make the remaining slip controlled and repeatable rather than assume it could be removed completely.

The factors we used to reduce unpredictable slip were:

Correct inner- and outer-wheel steering angles.
Accurate toe alignment when the servo is centered.
A rigid but accurately assembled chassis.
Tires with sufficient forward grip and moderate lateral compliance.
A low center of mass with enough load on both the steering and driving axles.
Four wheels making consistent contact with the surface.
Reduced speed before tight turns.
Encoder and IMU feedback to detect when actual movement differs from the commanded movement.

Turning radius

The geometric turning radius depends mainly on wheelbase and steering angle. A simplified bicycle model gives:

A shorter wheelbase or a greater steering angle reduces the theoretical radius. In practice, however, simply commanding a greater angle does not guarantee a tighter turn. Tire scrub, servo backlash, linkage deformation, insufficient torque, and wheel-to-chassis interference can make the real turning radius larger than the calculated value.

The servo linkage also creates a tradeoff between steering range, torque, and resolution. A long servo horn can provide more wheel travel but reduces mechanical advantage and makes each servo step produce a larger wheel-angle change. A shorter horn improves force and angular resolution but may not provide enough steering range. We selected the horn length and steering-arm geometry through CAD interference checks and physical testing.

Final mechanical integration

The final system combines:

A Pololu 25D Metal Gearmotor 20.4:1 HP 12 V with 48 CPR Encoder (#3203) for propulsion and wheel-motion feedback. A mechanically coupled driving axle, compliant with the non-differential-drive requirement.
A double-helical printed transmission for compact and smooth power transfer.
One HS-85MG servo controlling both steering wheels.
Ackermann-oriented steering arms so that the inside wheel turns farther than the outside wheel. Mechanical steering limits to prevent the servo from forcing the linkage beyond its safe range.
Encoder and BNO085 feedback to compare commanded movement with actual displacement and heading.
ToF wall measurements to correct accumulated movement errors.

The mechanical design and software controller were developed together. The steering geometry reduces predictable tire scrub, while the encoder, IMU, and ToF fusion compensate for errors that cannot be eliminated mechanically.

One iteration directly changed the final mechanism. Early track tests showed that the front tires scrubbed and the vehicle followed a wider path than commanded. The team recalculated the steering geometry from the real wheelbase and track width, implemented Ackermann-oriented steering arms, and shifted load toward the front axle. The resulting path was visibly smoother and no longer showed the original obvious overshoot; the remaining quantitative checks are listed in the verification procedure below and the complete problem-change-result record is preserved in ERR-MEC-001.

Verification procedure

To validate the assembly, we use the following checks:

1. Center the servo electronically and verify that both front wheels have the intended neutral toe.
2. Move the steering slowly in both directions and measure the dead band caused by backlash.
3. Measure the inside and outside wheel angles at several servo commands.
4. Verify that no steering link, wheel, or servo horn collides with the chassis.
5. Confirm that all four wheels remain in contact with a flat surface.

R ≈

### tan(δ)

L

## K WATERMAR ARK WATERMARK WAT RMARK WATERMARK WATERMA

## ATERMARK WATERMARK WATERMARK WA

## K WATERMARK WATERMARK WATERMARK WATERMA

## ARK WATERMARK WATERMARK WATERMARK WATERMARK WA

## RMARK WATERMARK WATERMARK WATERMARK WATERMARK WATERMA TERMARK WATERMARK WATERMARK WATERMARK WATERMARK WATERMARK

6. Measure the minimum left and right turning radii at low speed.
7. Repeat the radius test at higher speed and observe tire scrub or trajectory changes.
8. Compare encoder-estimated travel with measured vehicle displacement.
9. Repeat the tests after disassembly and reassembly to evaluate mechanical repeatability.

These measurements allow the geometry and controller values to be based on evidence rather than visual judgment alone.

Technical reference:

WRO 2026 Future Engineers General Rules, Sections 11.3, 11.5, and 11.13 (https://wro-association.org/wp-content/uploads/WRO-2026-Future-Engineers-Self-Driving-Cars-General-Rules.pdf)

### 4.3 Sensor Changes

### 4.3.1 Sensor Candidates

One of the most significant changes in this iteration was the sensing architecture. None of the sensors from the previous version were reused without first evaluating alternative technologies.

The candidates were grouped according to their intended function:

Category | Candidate sensors | Intended purpose
Distance sensing | HC-SR04, URM09, VL6180X, VL53L0X, VL53L1X, VL53L8CX, and RPLIDAR C1 | Wall detection, obstacle detection, and distance control
Position and odometry | SparkFun OTOS and Pololu 25D wheel encoders | Estimation of displacement, orientation, and vehicle position
Reference and color detection | Photoresistors, TCS-series sensors, and ALS-PT19 | Detection of lighting, colors, and visual track references
Visual perception | Raspberry Pi Camera Module 3, OpenMV Cam H7, and OpenMV N6 | Object classification, color recognition, and image-based navigation

The candidates were compared according to cost, measurement range, field of view, update rate, power consumption, communication interface, environmental resistance, and expected reliability on the competition field. Price was not treated as the only selection criterion: a low-cost sensor can have a long advertised range while still producing unstable measurements on angled surfaces, dark objects, or under strong ambient light.

### 4.3.2 Distance Sensing

We evaluated ultrasonic sensors, single-zone ToF sensors, a multizone ToF sensor, and a rotating 2D LiDAR. The comparison considered not only maximum advertised range, but also update rate, field of view, ambient-light resistance, target reflectivity, power consumption, cost, and behavior while the robot was moving.

The reliability ratings below describe suitability for our moving WRO vehicle and are based on both datasheet information and our own tests. They are not general ratings of the manufacturing quality of each sensing technology.

Sensor | Approx. price | Measurement type | Interface | Maximum update rate | Nominal range | Supply and consumption | Reliability and observed behavior
HC-SR04 | US$1–3 | Single-direction ultrasonic | Trigger/Echo GPIO | Approximately 16 Hz recommended | 2–400 cm | 5 V, approximately 15 mA | Low. Results varied considerably between manufacturers, and the origin and quality of generic modules were difficult to verify. Measurements were especially inconsistent while the robot was moving.

## K WATERMAR ARK WATERMARK WAT RMARK WATERMARK WATERMA

## ATERMARK WATERMARK WATERMARK WA

## K WATERMARK WATERMARK WATERMARK WATERMA

## ARK WATERMARK WATERMARK WATERMARK WATERMARK WA

## RMARK WATERMARK WATERMARK WATERMARK WATERMARK WATERMA TERMARK WATERMARK WATERMARK WATERMARK WATERMARK WATERMARK

Sensor | Approx. price | Measurement type | Interface | Maximum update rate | Nominal range | Supply and consumption | Reliability and observed behavior
DFRobot URM09 | US$12– 20 | Single-direction ultrasonic | I2C | Up to 50 Hz | 2–500 cm | 3.3–5.5 V, approximately 20 mA | Medium. It produced usable measurements at approximately 150 cm while the vehicle was moving quickly. However, its wide 60° field of view caused it to detect adjacent walls in narrow sections of the field.
VL6180X | US$1.50– 4 | Single-zone ToF | I2C | 10 Hz in the reference low-power configuration | 0–10 cm | Generic modules usually accept 3.3–5 V; approximately 1.7 mA average at 10 Hz | High only at very short distances. Its limited range made it unsuitable for the main wall-distance system.
VL53L0X | US$2.50– 5 | Single-zone ToF | I2C | Approximately 30 Hz with a 33 ms timing budget | Up to 200 cm | Generic modules usually accept 3.3–5 V; approximately 19 mA while ranging | Medium. In our tests, its performance against dark surfaces and ambient light was similar to or worse than that of the VL53L8CX. It also returned only one distance value per sensor.
VL53L1X | US$4.50– 8 | Single-zone ToF with adjustable region of interest | I2C | Up to 50 Hz | Up to 400 cm | Generic modules usually accept 3.3–5 V; approximately 16 mA while ranging | Medium to high. Its advertised range was greater than required, but in most of our tests it did not provide a significant reliability advantage over the VL53L8CX.
VL53L8CX | US$20–
30

4×4 or 8×8
multizone ToF
depth sensor
I2C or SPI | Up to 60 Hz at
4×4; up to 15
Hz at 8×8

2–400 cm per
zone

Carrier-board
dependent;
approximately
215 mW in
continuous
mode

High for our use
case. Black walls
were normally
detected from
approximately 80–
100 cm, which was
sufficient for
control. It was the
most resistant ToF
sensor to changing
ambient-light
conditions and
provided multiple

## K WATERMAR ARK WATERMARK WAT RMARK WATERMARK WATERMA

## ATERMARK WATERMARK WATERMARK WA

## K WATERMARK WATERMARK WATERMARK WATERMA

## ARK WATERMARK WATERMARK WATERMARK WATERMARK WA

## RMARK WATERMARK WATERMARK WATERMARK WATERMARK WATERMA TERMARK WATERMARK WATERMARK WATERMARK WATERMARK WATERMARK

Sensor | Approx. price | Measurement type | Interface | Maximum update rate | Nominal range | Supply and consumption | Reliability and observed behavior
| | | | | | | distance zones in every frame.
RPLIDAR C1 | US$80– 100 | 360° rotating 2D direct ToF LiDAR | TTL UART at 460800 baud | 8–12 complete scans/s specified; approximately 5 complete scans/s observed in our system | 5–1200 cm on white targets and approximately 5–600 cm on black targets | 5 V, approximately 230 mA while operating and up to 800 mA during startup | High spatial accuracy, but low temporal suitability at our vehicle speed. Its approximately 5 Hz effective scan rate caused the map to become outdated while the robot was moving quickly.

Why we selected the VL53L8CX

Our tests showed that the VL53L8CX was the most appropriate sensor for the new vehicle. It did not reliably detect the competition's black wall beyond 1 m, and under some conditions its maximum useful range was approximately 80 cm. This was sufficient because our controller did not require a complete long-range map of the field.

The main reason for selecting it was its resistance to changing ambient-light conditions. The lighting at the competition venue cannot be predicted, so robustness under different ambient-light levels was more important to us than maximum theoretical range. The single-zone VL53 sensors performed similarly or worse in most of our tests.

The VL53L8CX also returns a depth grid instead of one distance. This allows the software to compare neighboring zones, reject invalid readings, and obtain information about the position of a nearby wall without depending on a single measurement. Four compact sensors can be positioned around the robot to observe only the directions required by the controller.

Why we did not retain the RPLIDAR C1

The RPLIDAR C1 could detect the black wall at approximately 6 m and generally produced more precise long-range measurements. However, that range was not necessary for our control strategy.

The LiDAR generates approximately 5,000 individual distance samples per second, but these samples are distributed over a complete 360° rotation. This must not be confused with the rate at which the controller receives a complete scan. Although the manufacturer specifies 8– 12 rotations per second, our complete acquisition and processing pipeline normally produced approximately 5 usable scans per second.

At high vehicle speeds, the robot changed position significantly between complete LiDAR scans. Sensor fusion reduced this problem but could not remove the latency already present in the measurements. For our application, a shorter sensing range with more useful local information was preferable to a long-range 360° map that was updated too slowly.

Sensor fusion with wheel encoders

The new robot combines the quadrature encoder integrated into the Pololu #3203 25D gearmotor with the VL53L8CX measurements. The encoder provides high-frequency relative motion information between ToF frames, while the ToF sensors provide external references to nearby walls.

Consequently, the ToF sensors do not need to observe the entire field continuously. Encoder odometry estimates the robot's movement when no suitable wall is visible, and valid ToF measurements are used to correct accumulated position and orientation error when a wall enters the useful measurement range.

This architecture provided a better balance between environmental robustness, useful update rate, short-range wall detection, processing requirements, power consumption, cost, and mechanical simplicity.

Technical references:

HC-SR04 datasheet (https://www.digikey.com/en/htmldatasheets/production/3822706/0/0/1/hc-sr04.html)
DFRobot URM09 specifications (https://wiki.dfrobot.com/sen0304/) STMicroelectronics VL6180X datasheet (https://www.st.com/en/datasheet/vl6180x.pdf) STMicroelectronics VL53L0X datasheet (https://www.st.com/resource/en/datasheet/vl53l0x.pdf) STMicroelectronics VL53L1X datasheet (https://www.st.com/resource/en/datasheet/vl53l1x.pdf) STMicroelectronics VL53L8CX datasheet (https://www.st.com/resource/en/datasheet/vl53l8cx.pdf)

## K WATERMAR ARK WATERMARK WAT RMARK WATERMARK WATERMA

## ATERMARK WATERMARK WATERMARK WA

## K WATERMARK WATERMARK WATERMARK WATERMA

## ARK WATERMARK WATERMARK WATERMARK WATERMARK WA

## RMARK WATERMARK WATERMARK WATERMARK WATERMARK WATERMA TERMARK WATERMARK WATERMARK WATERMARK WATERMARK WATERMARK

SLAMTEC RPLIDAR C1 specifications (https://www.slamtec.com/en/c1/spec)

### 4.3.3 Position and Movement

Last year, we used a SparkFun Optical Tracking Odometry Sensor (OTOS). The OTOS combines an optical tracking sensor, a six-axis IMU, and an onboard microcontroller that performs sensor fusion. It directly provides planar position (x and y) and heading, so it can perform part of the work normally divided between wheel encoders and an IMU.

It was good enough for the previous robot, but our tests showed consistency and reliability problems at low speeds. Its optical
measurement also depended on its mounting height and on the texture, color, and illumination of the floor. Because the competition venue can have environmental conditions that differ from our workshop, we decided to replace this single-source position estimate with separate sensors whose information could be fused and independently verified.

What an IMU measures

An Inertial Measurement Unit (IMU) does not directly measure the robot's global position. A typical six-axis IMU contains:

A three-axis gyroscope, which measures angular velocity. Integrating this velocity provides changes in yaw, pitch, and roll, but small bias errors accumulate into drift.
A three-axis accelerometer, which measures specific force, including gravity. Gravity can help stabilize pitch and roll, but an accelerometer cannot provide an absolute yaw reference.

A nine-axis orientation system also includes a three-axis magnetometer. The magnetometer measures Earth's magnetic field and can provide an absolute heading reference, but its readings are easily disturbed by motors, high-current wiring, magnets, steel fasteners, and the magnetic characteristics of the venue.

An IMU does not necessarily perform sensor fusion by itself. Low-cost modules often provide only raw accelerometer, gyroscope, and magnetometer readings. Devices such as the BNO055 and BNO085 include an internal processor that combines these measurements and provides orientation outputs such as rotation vectors, yaw, pitch, and roll.

Drift and environmental interference

Drift is not one single error and it cannot be completely removed simply by purchasing a more expensive sensor:

Gyroscope bias accumulates when angular velocity is integrated over time.
Magnetometer interference changes the apparent direction of magnetic north.
Wheel encoders measure wheel rotation, but their position estimate accumulates error when the wheels slip.
Optical odometry depends on the floor texture, sensor height, illumination, and whether the surface provides enough visible detail. Accelerometer integration amplifies small noise and bias errors, making it unsuitable as the only long-term position estimate.

A robot can therefore work correctly at our school and behave differently at the competition venue. The magnetic field, lighting, floor material, mechanical vibration, and nearby electrical equipment can all affect its sensors.

The main methods we considered for reducing these errors were:

1. Mechanical and electrical placement: keeping the IMU away from motors, magnets, high-current wires, and switching power components.
2. Gyroscope calibration: estimating the stationary zero-rate bias before the robot begins moving.
3. Hard-iron calibration: removing a constant magnetometer offset caused by permanent magnetic fields on the robot.
4. Soft-iron calibration: compensating for the scaling and distortion produced by nearby ferromagnetic materials.
5. Sensor-fusion filters: using complementary, Kalman, or manufacturer-provided fusion algorithms to combine measurements according to their strengths.
6. External corrections: using wall measurements, visual references, or a map to correct the accumulated error of relative sensors.

More expensive fused IMUs reduce the amount of filtering software that the team must develop, but they still require correct mounting, calibration, configuration, and testing in the completed robot.

Position and orientation comparison

The GY prefix does not identify a specific sensor or manufacturer. It is commonly used for generic breakout-board designs, and two boards with the same printed name can contain different or substituted integrated circuits. For this reason, the exact chip marking, I2C identification register, schematic, regulator, and logic-voltage compatibility must be verified before comparing or using one of these modules.

## K WATERMAR ARK WATERMARK WAT RMARK WATERMARK WATERMA

## ATERMARK WATERMARK WATERMARK WA

## K WATERMARK WATERMARK WATERMARK WATERMA

## ARK WATERMARK WATERMARK WATERMARK WATERMARK WA

## RMARK WATERMARK WATERMARK WATERMARK WATERMARK WATERMA TERMARK WATERMARK WATERMARK WATERMARK WATERMARK WATERMARK

Device | Measurement principle | Approx. price | Interface and output | Update capability | Reliability in our application | Main limitation
SparkFun OTOS | Optical floor tracking plus six-axis IMU and onboard fusion | US$84.95 | I2C; x, y, heading, velocity, and acceleration | Optical sensor operates internally at up to 20,000 frames/s | Medium. It worked better during faster movement, but our low-speed results were inconsistent. | Depends strongly on floor characteristics, mounting distance, calibration, and illumination.
GY-521 / MPU-6050 | Generic six-axis accelerometer and gyroscope module | US$1–6 | I2C; mainly raw acceleration, angular velocity, and temperature | Gyroscope sampling up to 8 kHz; practical fused output depends on the host processor and filter | Low to medium. Acceptable for experiments after calibration, but module quality and offsets vary considerably. | No magnetometer or dependable ready-to-use heading; requires host-side calibration and sensor fusion.
GY-85 | Generic multi-chip nine-axis module, commonly using ADXL345, ITG3205, and HMC5883L-compatible devices | US$4–9 | I2C; separate raw accelerometer, gyroscope, and magnetometer readings | No unified fused rate; practical fusion commonly runs at approximately 50–200 Hz | Low to medium. It can work after extensive calibration, but consistency between sellers is difficult to guarantee. | Old multi-chip design; replacement magnetometers and clone components are common, and all fusion must be implemented by the host.
GY-91 / GY-9250 | Generic nine-axis MPU-9250-class IMU, often combined with a BMP280 barometer | US$5–12 | I2C or SPI; raw acceleration, angular velocity, magnetic field, and pressure | High-rate gyro/accelerometer data; magnetometer updates up to approximately 100 Hz | Medium only after verification and calibration. A genuine device can produce good results with a well-designed filter. | Advertised MPU-9250 boards may contain substituted MPU-6500 or other chips; no trustworthy plug-and-play fused orientation.
BNO055 | Nine-axis IMU with onboard BSX3.0 fusion | US$30–35 | I2C or UART; fused Euler angles, quaternion, and raw sensor data | Fused orientation up to approximately 100 Hz | Good. Easier to integrate than a raw low-cost IMU, but less robust than the BNO085 in our tests. | Older device, sensitive to magnetic interference, and Bosch does not recommend it for new designs.
BNO085 | Nine-axis IMU with SH-2 onboard sensor fusion | US$25–35 | I2C, SPI, or UART; multiple rotation-vector and calibrated sensor reports | Common fused reports at 100–400 Hz, depending on configuration | High. It provided the most stable orientation output of the evaluated IMUs and reduced the fusion work required on the Teensy. | Magnetometer-assisted outputs can still be disturbed by motors and the venue's magnetic field.

Pololu 25D
quadrature
encoder

Incremental
wheel rotation

Included
with the
US$56.95
gearmotor

Two digital
quadrature
channels; ticks,
direction, speed,

Pulse rate increases
directly with wheel
speed

High for wheel
rotation and
speed control. It
remains usable
at speeds where

Cannot detect wheel
slip and
accumulates
position error

## K WATERMAR ARK WATERMARK WAT RMARK WATERMARK WATERMA

## ATERMARK WATERMARK WATERMARK WA

## K WATERMARK WATERMARK WATERMARK WATERMA

## ARK WATERMARK WATERMARK WATERMARK WATERMARK WA

## RMARK WATERMARK WATERMARK WATERMARK WATERMARK WATERMA TERMARK WATERMARK WATERMARK WATERMARK WATERMARK WATERMARK

Device | Measurement principle | Approx. price | Interface and output | Update capability | Reliability in our application | Main limitation
| | | and relative distance | | the OTOS was inconsistent. | without an external reference.

Final position-estimation architecture

We selected the BNO085 and the integrated Pololu 25D motor encoder instead of relying on the OTOS as a single position source:

The encoder provides high-rate wheel displacement and velocity feedback, including during low-speed maneuvers.
The BNO085 provides heading and angular-motion information with onboard sensor fusion.
The VL53L8CX sensors provide external wall references that can correct accumulated relative-position errors.

This architecture deliberately uses complementary sensors. The encoder remains reliable when no wall is visible, the IMU tracks changes in orientation, and the ToF sensors correct the estimate whenever a valid wall measurement becomes available. A failure or temporary loss of one reference therefore does not immediately remove all movement information from the controller.

Technical references:

SparkFun OTOS product specifications (https://www.sparkfun.com/sparkfun-optical-tracking-odometry-sensor-paa5160e1-qwiic.html)
SparkFun OTOS hardware overview (https://docs.sparkfun.com/SparkFun_Optical_Tracking_Odometry_Sensor/hardware_overview/)
TDK InvenSense MPU-6050 product specification (https://invensense.tdk.com/wp-content/uploads/2015/02/MPU-6000-Datasheet1.pdf) TDK InvenSense MPU-9250 register map (https://invensense.tdk.com/wp-content/uploads/2015/02/RM-MPU-9250A-00-v1.6.pdf)
Bosch BNO055 product information (https://www.bosch-sensortec.com/products/smart-sensors/bno055/)
CEVA BNO08X datasheet (https://www.ceva-ip.com/wp-content/uploads/BNO080_085-Datasheet.pdf)

### 4.3.4 Cameras

Cameras are optical sensors, but selecting one for a robot involves more than comparing image resolution. The camera, processor, image-transfer interface, available algorithms, exposure controls, frame rate, power consumption, and software environment together determine whether the complete vision system is suitable.

A camera's advertised frame rate is also not necessarily the rate at which the robot receives useful detections. Image capture, color conversion, filtering, inference, and communication all add processing time. For this reason, we compared the rate of the complete detection pipeline rather than considering only the sensor's maximum FPS.

Vision-system categories

The evaluated systems can be divided into three practical categories:

1. Fixed-function smart vision sensors: Devices such as Pixy2 and HUSKYLENS process images internally and send compact results through UART, I2C, SPI, or USB. They are easy to connect to a microcontroller, but the available algorithms and image controls are more restricted. HUSKYLENS 2 can deploy custom trained models, although its processing pipeline is still less open than a general-purpose programmable camera.
2. Programmable embedded-vision boards: OpenMV and MaixCam combine a camera with an MCU or AI SoC. User code runs directly on the board, allowing calibration, regions of interest, color thresholds, filtering, and custom communication protocols without adding a Linux computer.
3. Camera modules with external processing: A sensor such as Raspberry Pi Camera Module 3 sends image data to an SBC through a high-bandwidth interface such as MIPI CSI-2. The SBC can run OpenCV or neural-network frameworks and provides the greatest flexibility, but requires more space, power, startup time, and software maintenance.

These categories are independent of whether a product contains an FPGA, MCU, GPU, or NPU. For example, the OpenMV H7 uses an STM32 microcontroller, the OpenMV N6 includes an NPU, and HUSKYLENS 2 uses a Kendryte AI SoC. FPGA-based cameras also exist, but an FPGA is not required for a camera to process images internally.

I2C is generally too slow for transferring complete video frames. On image sensors, it is commonly used to configure exposure, gain, resolution, and other registers. Full images are normally transferred through a parallel camera bus, MIPI CSI-2, USB, or another high-bandwidth connection. Smart cameras can use I2C or UART because they send only small results, such as an object's position and size, rather than the complete image.

Camera-system comparison

## K WATERMAR ARK WATERMARK WAT RMARK WATERMARK WATERMA

## ATERMARK WATERMARK WATERMARK WA

## K WATERMARK WATERMARK WATERMARK WATERMA

## ARK WATERMARK WATERMARK WATERMARK WATERMARK WA

## RMARK WATERMARK WATERMARK WATERMARK WATERMARK WATERMA TERMARK WATERMARK WATERMARK WATERMARK WATERMARK WATERMARK

Vision system | Architecture | Approx. price | Programmability | Camera or processing rate | Output to main controller | Reliability and main limitation
ESP32-CAM / OV2640 | Camera sensor with low-cost MCU | US$5–12 | Arduino/C++ or ESP-IDF | Approximately 10– 30 useful FPS at reduced resolutions, depending on processing | UART, Wi-Fi, or application-specific protocol | Low to medium for advanced vision. Inexpensive and compact, but RAM and processing power limit filtering, resolution, and consistent high-rate detection.
Pixy2 | Fixed-function smart camera | US$60– 130 | Algorithms are mainly configured rather than freely programmed | Up to 60 processed frames/s | UART, I2C, SPI, USB, digital, or analog | Medium. Fast and simple for color signatures and line tracking, but offers limited control over the complete vision pipeline and adaptation to unusual lighting.
HUSKYLENS 2 | All-in-one AI vision sensor with Kendryte K230 SoC | US$80– 120 | Built-in models and deployment of trained custom models | 2 MP camera at up to 60 FPS; inference rate depends on the selected model | UART, I2C, USB-C, or optional Wi-Fi | Medium to high. Much more capable than earlier fixed-function cameras, but it is comparatively large, weighs 90 g, consumes 1.5–3 W, and provides less low-level pipeline control than OpenMV or an SBC.
OpenMV Cam H7 | Programmable embedded camera with STM32H743 MCU | US$80 | MicroPython through the OpenMV IDE | Sensor capture up to 75 FPS at VGA and up to 150 FPS below QVGA; algorithm rate depends on the script | UART, I2C, SPI, CAN, or USB | High for our color-detection task. Compact, predictable, and fully configurable, but has limited RAM and processing power compared with newer AI boards. This model is no longer in production.
OpenMV N6 | Programmable embedded camera with STM32N6 MCU and NPU | US$180– 195 | MicroPython, classical vision, and neural-network inference | 1 MP global-shutter sensor up to 120 FPS; YOLO inference at approximately 30 FPS | UART, I2C, SPI, USB-C, Ethernet, Wi-Fi, or Bluetooth | High for the current robot. The experimental firmware used by the team provides the white-balance control required by the color-detection pipeline.
MaixCam Lite | Programmable embedded AI camera | US$40– 70 | MaixPy/Python and deployable AI models | Typically up to approximately 60 FPS, depending on resolution and model | UART, USB, network, or application-specific interface | Medium in our evaluation. Good processing capability and size, but the available documentation and development workflow were less mature for our team.

Raspberry Pi
5 + Camera

Camera sensor
with external

US$85–
140

Fully
programmable

Camera supports
1080p50 and high-

UART, USB,
network, CAN

High when correctly
engineered. Provides

## K WATERMAR ARK WATERMARK WAT RMARK WATERMARK WATERMA

## ATERMARK WATERMARK WATERMARK WA

## K WATERMARK WATERMARK WATERMARK WATERMA

## ARK WATERMARK WATERMARK WATERMARK WATERMARK WA

## RMARK WATERMARK WATERMARK WATERMARK WATERMARK WATERMA TERMARK WATERMARK WATERMARK WATERMARK WATERMARK WATERMARK

Vision system | Architecture | Approx. price | Programmability | Camera or processing rate | Output to main controller | Reliability and main limitation
Module 3 | Linux SBC | combined | with Python/C++, OpenCV, and AI frameworks | frame-rate modes at lower resolutions | adapter, or other SBC interface | the most software flexibility, but consumes substantially more power, occupies more space, takes longer to boot, and increases system complexity.

Environmental reliability

A programmable camera does not automatically solve lighting problems, but it gives the team tools to control them. Important techniques include:

Locking or limiting automatic exposure after calibration.
Controlling white balance and sensor gain.
Defining regions of interest so irrelevant parts of the field are ignored.
Converting colors into a space that separates chromatic information from brightness. Filtering detections by area, aspect ratio, position, and temporal consistency.
Calibrating thresholds under bright, dark, warm, and cool illumination.
Rejecting detections that do not persist across multiple frames.

Fixed-function cameras can be reliable when the environment matches their expected conditions. However, if their internal processing cannot be adjusted sufficiently, a lighting change may produce errors that the main controller cannot correct because it never receives the original image.

Final decision

Our task only requires detecting red and green obstacles and transmitting a compact description of each valid object to the Teensy. Sending full video to the main controller would add bandwidth and processing requirements without improving the control decision.

The OpenMV N6 is installed in the current robot. It provides the global-shutter sensor and processing headroom needed for the vision pipeline while keeping the computation onboard. The team uses an experimental firmware that enables the white-balance control required for repeatable color detection.

The N6 program defines color thresholds and regions of interest, locks the relevant automatic image controls during calibration, rejects invalid blobs, and sends only the object's color and image position to the Teensy through UART. The robot does not transmit full video to the navigation controller.

Compared with a Raspberry Pi and Camera Module 3, the N6 starts quickly and keeps the vision stack on a compact embedded board. Compared with Pixy2 or HUSKYLENS, it preserves direct control over calibration and filtering while providing more processing capacity for future work.

Technical references:

Pixy2 communication and 60 FPS processing (https://docs.pixycam.com/wiki/doku.php?id=wiki:v3:porting_guide) HUSKYLENS 2 specifications (https://wiki.dfrobot.com/sen0638/)
OpenMV Cam H7 specifications (https://openmv.io/products/openmv-cam-h7)
OpenMV N6 specifications (https://openmv.io/products/openmv-n6)
Raspberry Pi Camera Module 3 product brief (https://datasheets.raspberrypi.com/camera/camera-module-3-product-brief.pdf)

### 4.4 Controller and Electrical Architecture Decisions

The final control architecture keeps deterministic vehicle control and ToF acquisition on the Teensy 4.0. The Seeed Studio XIAO ESP32-C6 is retained as a development telemetry bridge, so wireless debugging remains outside the competition-time control loop.

MCU | Clock speed | Observed PWM behavior | Decision
Teensy 4.0 | 600 MHz | Excellent; smooth startup and useful torque at low duty cycles | Selected as the main controller

## K WATERMAR ARK WATERMARK WAT RMARK WATERMARK WATERMA

## ATERMARK WATERMARK WATERMARK WA

## K WATERMARK WATERMARK WATERMARK WATERMA

## ARK WATERMARK WATERMARK WATERMARK WATERMARK WA

## RMARK WATERMARK WATERMARK WATERMARK WATERMARK WATERMA TERMARK WATERMARK WATERMARK WATERMARK WATERMARK WATERMARK

MCU | Clock speed | Observed PWM behavior | Decision
Arduino Nano | 16 MHz | Good and predictable | Rejected because of its lower processing and interface capacity
Raspberry Pi Pico | 133 MHz | Inconsistent at very low duty cycles in our tested software configuration | Rejected for the main controller
Seeed Studio XIAO ESP32-C6 | 120 MHz | Good, with BLE available for development telemetry | Selected as the development telemetry bridge

These PWM observations are empirical results from our prototypes, not a general ranking of the microcontrollers. Timer configuration, resolution, SDK, and motor-driver implementation can change the result. Wireless telemetry is used only during development and is disabled during official runs.

The electrical design was consolidated into one 8 × 8 cm, two-layer PCB. A single board reduced interconnects and made the complete system smaller, while a top-mounted layout kept the controllers, power stage, and connectors accessible for repair. The final installed architecture is documented in Section 7.

## 5. Final Robot Architecture

Name: Pistonudo

Subsystem | Final implementation | Detailed section
Propulsion | Pololu 25D Metal Gearmotor 20.4:1 HP 12 V with 48 CPR Encoder (#3203), 500 RPM no-load, custom 1:1 double-helical transmission, and rigid rear axle | Mobility Management
Steering | HiTEC HS-85MG servo with Ackermann linkage | Mobility Management
Wall sensing | Four VL53L8CX multizone ToF sensors read directly by the Teensy 4.0 | Sensor R&D
Position and heading | Pololu encoder, BNO085, and valid wall references | Position and Movement
Obstacle perception | OpenMV N6 color detection | Obstacle Management
Main control | Teensy 4.0 running the navigation state machine and actuator control | Software Architecture
Electrical integration | Single 8 × 8 cm PCB with regulated power, motor driver, controllers, and service connectors | Electronics

The table is the single overview of the completed robot. The R&D chapter explains why each option was selected; the subsystem chapters explain what was built; the software chapter explains how it operates; and the validation chapter records what has been measured.

### 5.1 Competition Version and Release Notes

Competition documentation version: WRO-2026-Competition-v1.0-rc1

Firmware baseline: 8de5c7b (https://github.com/chaBotsMX/chaBots-Tuneados-WRO-Future-Engineers-2026/commit/8de5c7bc375f2857ba302f1c0525ff1ad88d9a91)

Hardware configuration: Pistonudo with Teensy 4.0, four VL53L8CX sensors, BNO085, OpenMV N6, Pololu #3203 drive motor, and HS-85MG steering servo

Documentation date: 2026-09-07

This release candidate establishes one reproducible competition configuration for both Open and Obstacles. It replaces the earlier XIAO-based ToF architecture with direct Teensy SPI acquisition, records the N6 vision contracts, identifies the exact build targets, and defines the remaining field-validation entries. It becomes v1.0 when the final Open and Obstacles validation rows are completed against this configuration.

## K WATERMAR ARK WATERMARK WAT RMARK WATERMARK WATERMA

## ATERMARK WATERMARK WATERMARK WA

## K WATERMARK WATERMARK WATERMARK WATERMA

## ARK WATERMARK WATERMARK WATERMARK WATERMARK WA

## RMARK WATERMARK WATERMARK WATERMARK WATERMARK WATERMA TERMARK WATERMARK WATERMARK WATERMARK WATERMARK WATERMARK

The final publication commit should describe the delivered documentation explicitly, for example document WRO 2026 competition release candidate ; the existing history does not need to be rewritten.

### 5.2 Sensor Placement and Field Geometry

The four distance sensors are mounted orthogonally because each orientation answers a different question created by the rectangular WRO field. The front sensor detects an approaching outer wall and provides the distance threshold that begins a corner or blue-line turn. The left and right sensors observe the wall parallel to the current straight section; the controller selects the inside reference according to travel direction and uses the opposite side for close-wall protection. The rear sensor faces the space into which the vehicle reverses, providing a physical reference for reverse maneuvers and future recovery checks.

The OpenMV N6 is mounted above the chassis on the longitudinal centerline with a fixed forward angle. This position keeps both obstacle columns and the blue floor line inside its QVGA field of view while reducing occlusion by the front wheels and bumper. Its lower obstacle region supports red/green evasion, and its dedicated upper floor-line region provides the transition reference before the vehicle reaches a corner. The fixed bracket makes camera height and angle repeatable after transport; white balance, exposure, thresholds, and regions of interest are checked whenever field lighting changes.

Sensor | Orientation | Field feature observed | Decision supported
Front VL53L8CX | Forward | Outer wall at the end of a straight | Edge approach, corner entry, and blue-line maneuver threshold
Rear VL53L8CX | Backward | Clearance behind the vehicle | Reverse clearance and recovery diagnosis
Left VL53L8CX | 90° left | Left wall along straights and corners | Clockwise wall following and left-side protection
Right VL53L8CX | 90° right | Right wall along straights and corners | Counterclockwise wall following and right-side protection
OpenMV N6 | Forward, elevated, fixed angle | Red/green columns and colored floor lines | Obstacle side selection, direction selection, and turn sequencing

### 5.3 Robot Gallery

## K WATERMAR ARK WATERMARK WAT RMARK WATERMARK WATERMA

## ATERMARK WATERMARK WATERMARK WA

## K WATERMARK WATERMARK WATERMARK WATERMA

## ARK WATERMARK WATERMARK WATERMARK WATERMARK WA

## RMARK WATERMARK WATERMARK WATERMARK WATERMARK WATERMA TERMARK WATERMARK WATERMARK WATERMARK WATERMARK WATERMARK

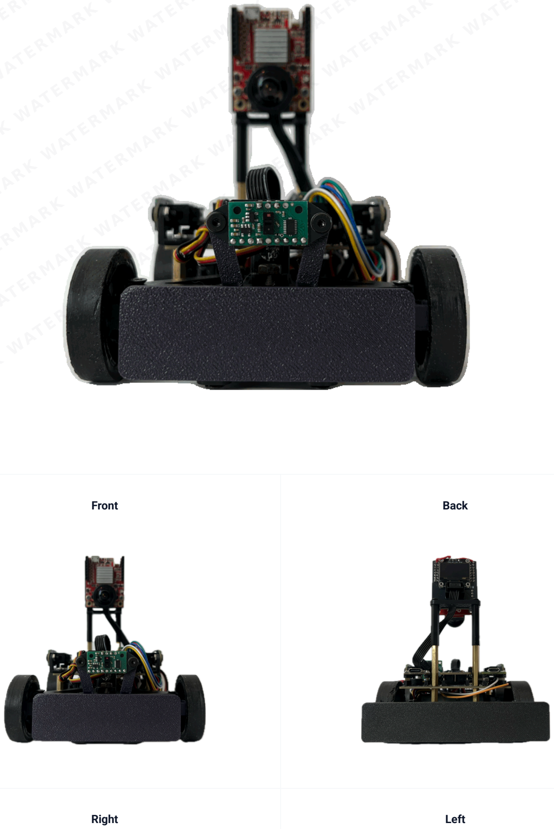
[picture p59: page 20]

Front | Back
Right | Left

## K WATERMAR ARK WATERMARK WAT RMARK WATERMARK WATERMA

## ATERMARK WATERMARK WATERMARK WA

## K WATERMARK WATERMARK WATERMARK WATERMA

## ARK WATERMARK WATERMARK WATERMARK WATERMARK WA

## RMARK WATERMARK WATERMARK WATERMARK WATERMARK WATERMA TERMARK WATERMARK WATERMARK WATERMARK WATERMARK WATERMARK

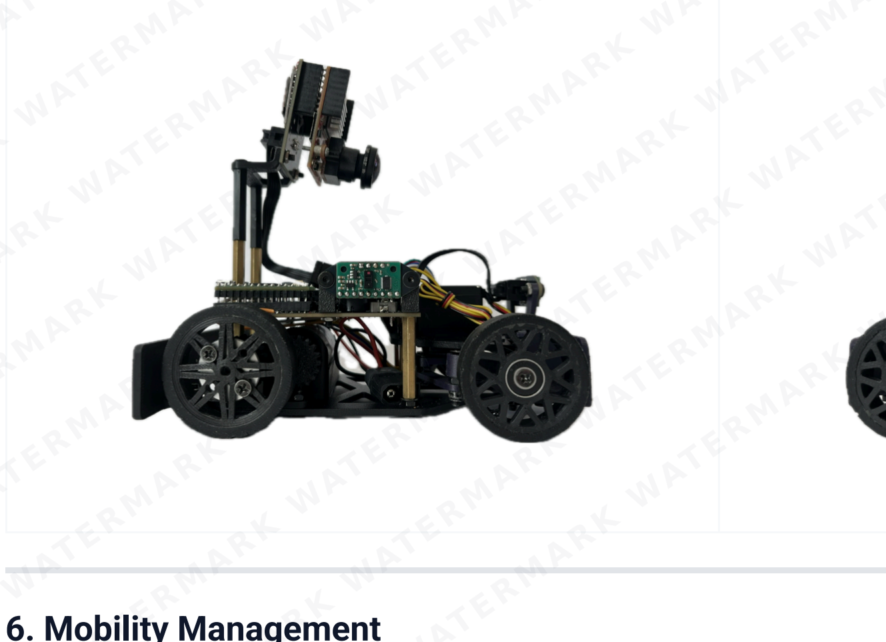
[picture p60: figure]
K WATERMAR ARK WATERMARK WAT RMARK WATERMARK WATERMA; ATERMARK WATERMARK WATERMARK WA; K WATERMARK WATERMARK WATERMARK WATERMA

## 6. Mobility Management

### 6.1 Gearbox

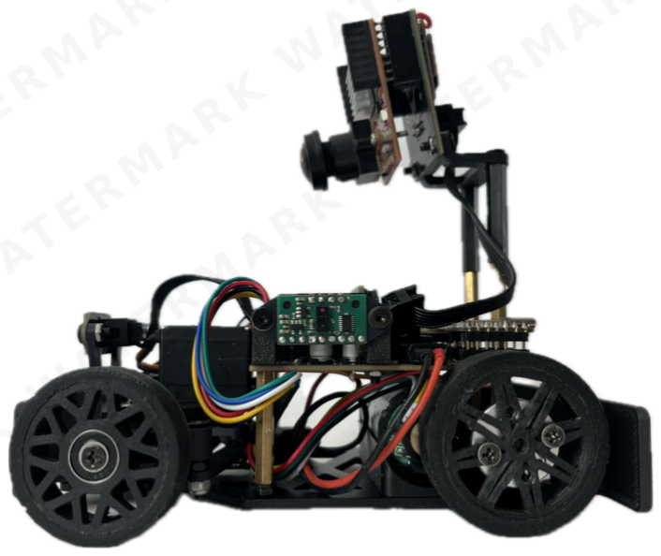
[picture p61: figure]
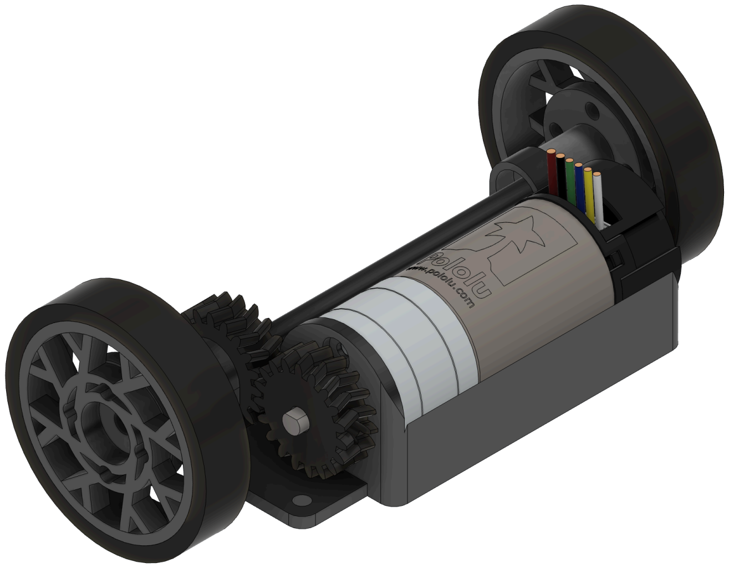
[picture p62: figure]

The robot's transmission features a custom-designed gearbox, with the base and gears developed in CAD software and manufactured in-house. For fabrication, the team used a Creality K2 Plus Combo printer, chosen for its reliability in handling engineering-grade materials. The material selected was Polymaker PETG-CF (a carbon-fiber-infused PETG), prized for its high stiffness, dimensional stability, and excellent wear resistance, which are critical for durable mechanical components.

A key design feature is the use of double helical gears. This geometry was chosen over standard spur gears to ensure smoother, quieter power transmission with reduced vibration and superior load distribution. This significantly improves mechanical efficiency and component lifespan.

The drive axle consists of 4 mm steel shafts, which were custom-cut from rod stock. To ensure positive torque transfer from the gearbox to the wheels, the ends of the shafts were manually modified using a Dremel tool to create a "D" shape. This profile prevents slippage between the shaft and the wheel hub, a common failure point in high-torque applications.

## ARK WATERMARK WATERMARK WATERMARK WATERMARK WA

## RMARK WATERMARK WATERMARK WATERMARK WATERMARK WATERMA TERMARK WATERMARK WATERMARK WATERMARK WATERMARK WATERMARK

Part | Description | Image

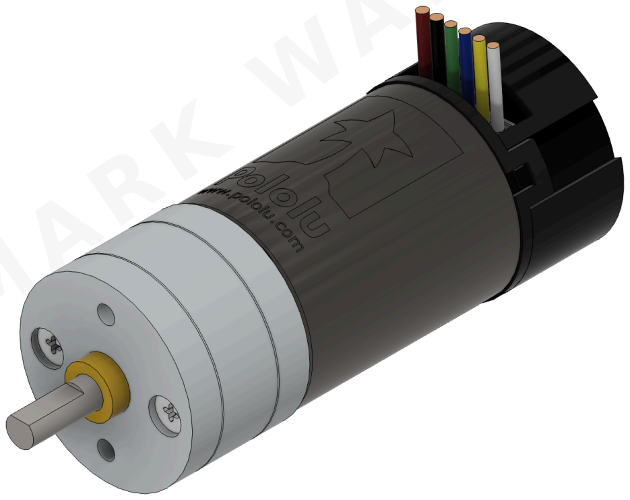
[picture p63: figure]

6.1.1 Pololu 25D Motor and Encoder | The installed drive unit is the Pololu 25D Metal Gearmotor 20.4:1 HP 12 V with 48 CPR Encoder, product #3203. Its approximately 500 RPM no-load output provides the required speed while the integrated gearbox supplies the reduction before the custom transmission. The quadrature encoder supplies wheel-motion feedback for distance and speed control.

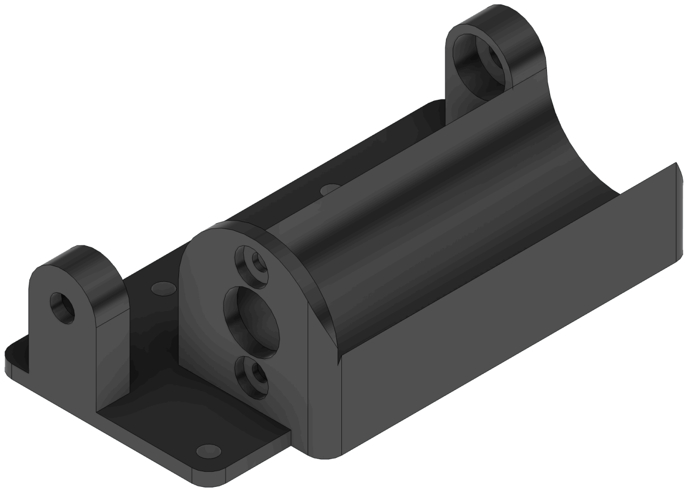
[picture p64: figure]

6.1.2 Base | We designed the base of the gearbox so that the wheel axle is as close as possible to the steering axis in order to make tighter turns.

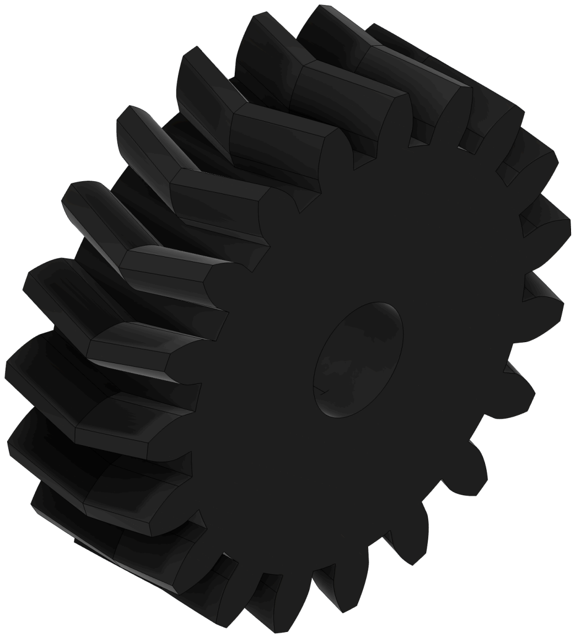
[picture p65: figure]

6.1.3 Gears | The custom-printed double-helical gears transfer power from the Pololu #3203 gearhead output to the rear axle. This external stage uses a 1:1 ratio, so it preserves the motor's approximately 500 RPM no-load output and the torque delivered by its internal 20.4:1 gearbox. The external gears exist to place the motor compactly and transmit power to the axle, not to add another reduction.
6.1.4 Rear Rim | The custom rear rim matches the larger driven-wheel diameter to the chassis ground clearance. Its D-profile hub provides positive torque transfer to the 4 mm axle, while the printed spoke structure keeps the part stiff without unnecessary material. The polyurethane tread supplies replaceable traction on the competition surface.

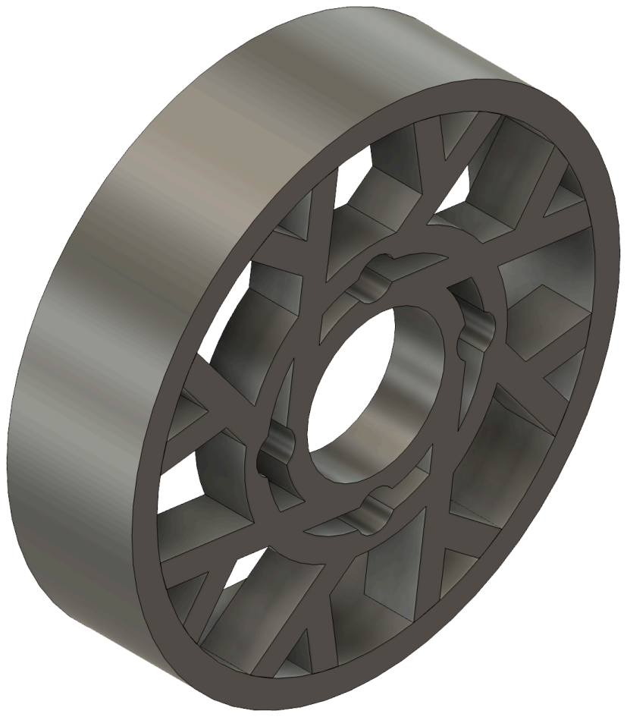
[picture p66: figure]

The motor CAD asset retains an earlier 9.7 reference in its filename because the geometry was imported during prototyping. It is an envelope and assembly reference only; the installed competition motor and every drivetrain calculation use Pololu #3203 with its 20.4:1 internal gearbox.

### 6.2 Steering System

## K WATERMAR ARK WATERMARK WAT RMARK WATERMARK WATERMA

## ATERMARK WATERMARK WATERMARK WA

## K WATERMARK WATERMARK WATERMARK WATERMA

## ARK WATERMARK WATERMARK WATERMARK WATERMARK WA

## RMARK WATERMARK WATERMARK WATERMARK WATERMARK WATERMA TERMARK WATERMARK WATERMARK WATERMARK WATERMARK WATERMARK

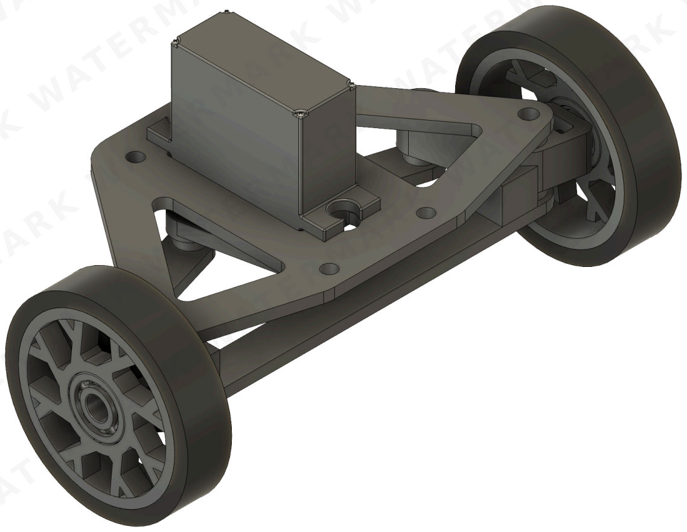
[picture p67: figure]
K WATERMAR ARK WATERMARK WAT RMARK WATERMARK WATERMA; ATERMARK WATERMARK WATERMARK WA; K WATERMARK WATERMARK WATERMARK WATERMA

For the steering system, the goal was to simplify the mechanism so it could be manufactured and repaired quickly. We selected Ackermann geometry so the inner wheel can turn farther than the outer wheel. This reduces geometric tire scrub during a turn, although tire deformation, axle coupling, surface grip, and alignment can still produce slip.

Part | Description | Image

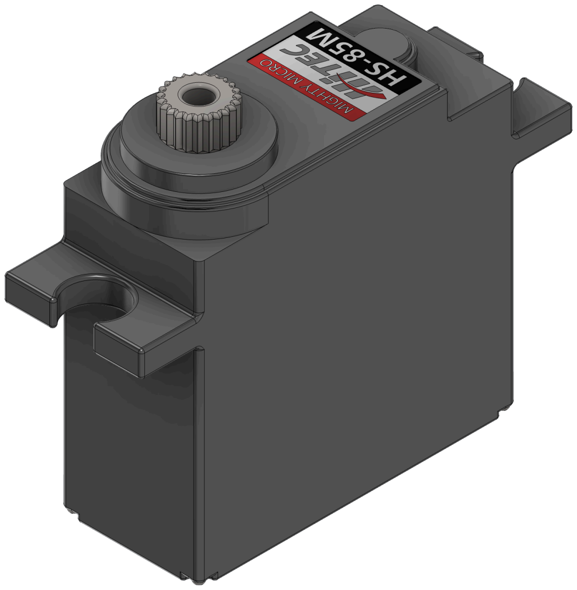
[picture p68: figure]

6.2.1 Servo
HiTEC HS-85MG

We selected the HiTEC HS-85MG for our robot's Ackermann steering system, primarily due to its robust metal gears (MG). Unlike many standard or smaller servos that use plastic gears, the metal gearing provides the significantly enhanced durability and resistance to stripping that our steering mechanism requires. This is crucial for us to handle the mechanical loads, vibrations, and potential impacts inherent in the system's operation. We also find that this servo packs considerable torque and good precision into a compact "mighty mini" form factor, supported by a top ball bearing. This ensures it provides the strength we need to turn the wheels effectively while maintaining accurate steering angles, minimizing the excessive "slop" or backlash we might see in less robust options. For application, this blend of power, durability, and reliable accuracy in a small package makes it a superior choice over servos that could fail or wear quickly under the demands of steering.

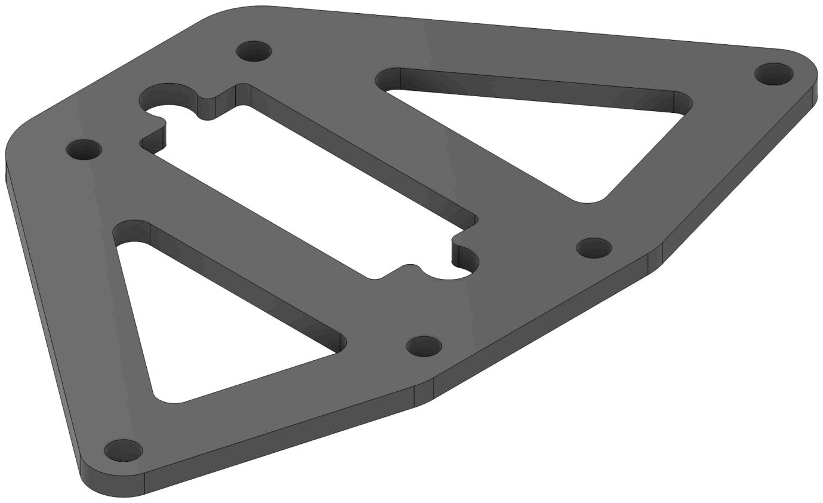
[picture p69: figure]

6.2.2 Base | We designed the base around the servo, so that everything was symmetrical. We also designed the base to be modular and easily attach to the robot's chassis for easy repairs. This part is made out of stainless steel in order to balance the robot's center of mass.

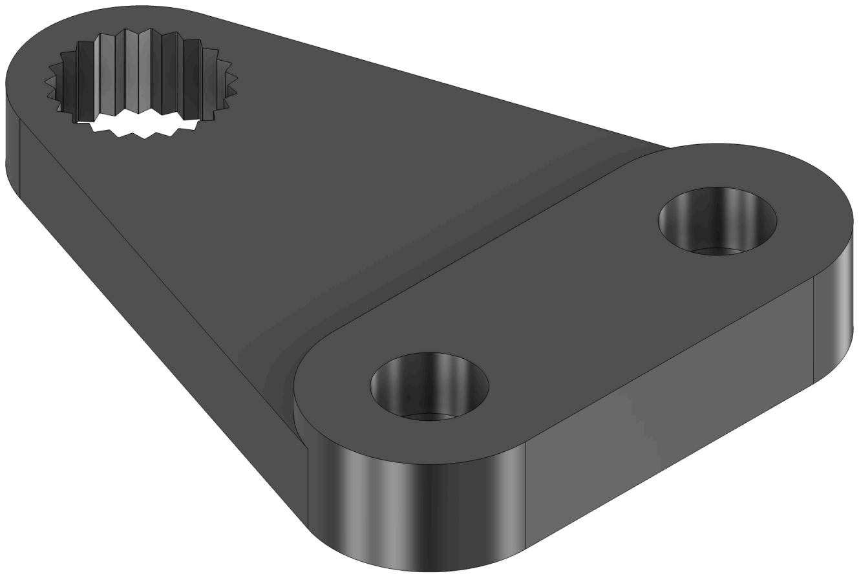
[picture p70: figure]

6.2.3 Servo Connector | We designed the servo connector this way because, as an Ackermann system, the wheels needed to be connected independently of each other. If we used a single connector for the wheels, both would have the same turning angle, but by splitting it, each wheel would turn at a different angle.

## ARK WATERMARK WATERMARK WATERMARK WATERMARK WA

## RMARK WATERMARK WATERMARK WATERMARK WATERMARK WATERMA TERMARK WATERMARK WATERMARK WATERMARK WATERMARK WATERMARK

Part | Description | Image

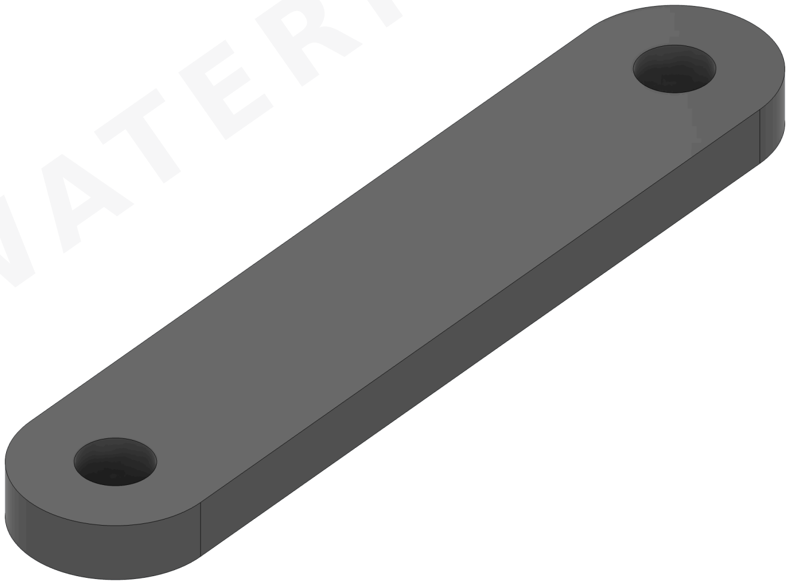
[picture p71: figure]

6.2.4 Bracket Connectors | As mentioned above, we used two connectors, one per wheel, so they rotated independently.

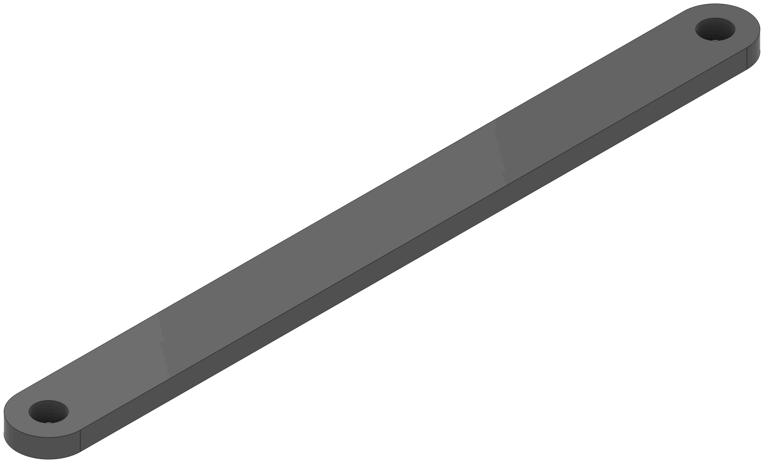
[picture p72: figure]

6.2.5 Stabilizer | This stabilizer bar is to prevent the wheel brackets from having play and to make them more stable.

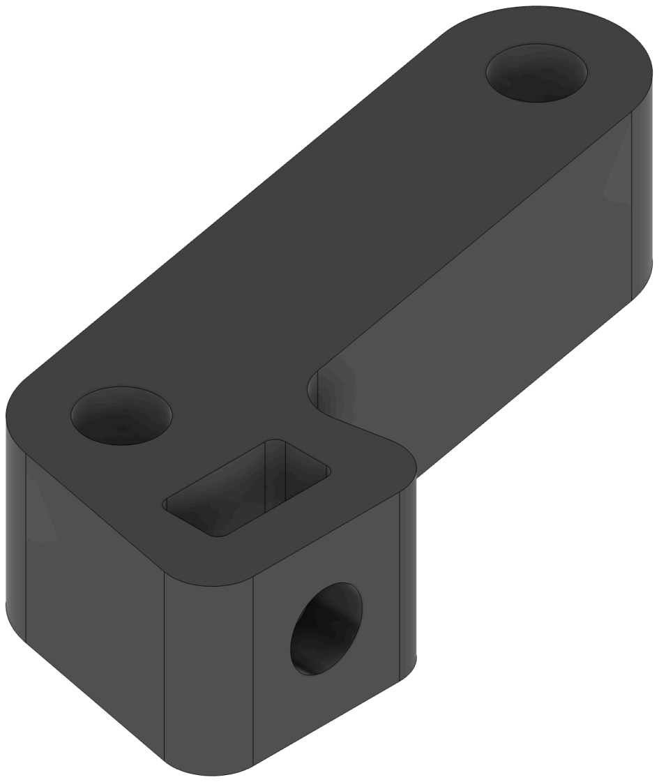
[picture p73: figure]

6.2.6 Wheel Bracket | We designed the wheel mount with an angle in order that the line projected collides in the center of the rear axis.

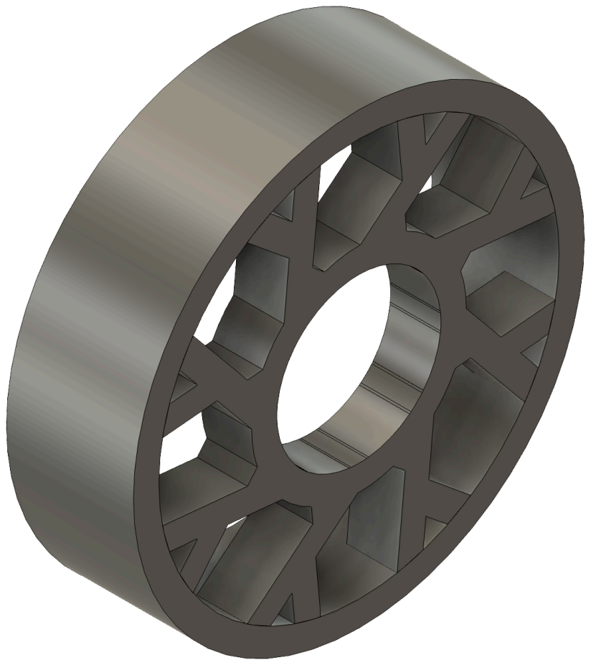
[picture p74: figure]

6.2.7 Rim S

The rim s represents the compact version of our wheel assembly, designed specifically to attach to the front wheel mounts via a bearing. This smaller variant is crucial for maintaining the robot's horizontal alignment, counterbalancing the weight of the larger rear drive wheels to achieve a perfectly level center of gravity. Engineered for low-friction rotation and high maneuverability, the rim features an optimized profile that reduces rotational inertia. Subsequently, we use a mold and A40 polyurethane resin to manufacture the rubber component. This process is shown in the following video: WRO FutureEngineers Custom Wheels - chaBots NERV (https://youtu.be/8JH6QCOU_B0)

### 6.3 Camera Mount

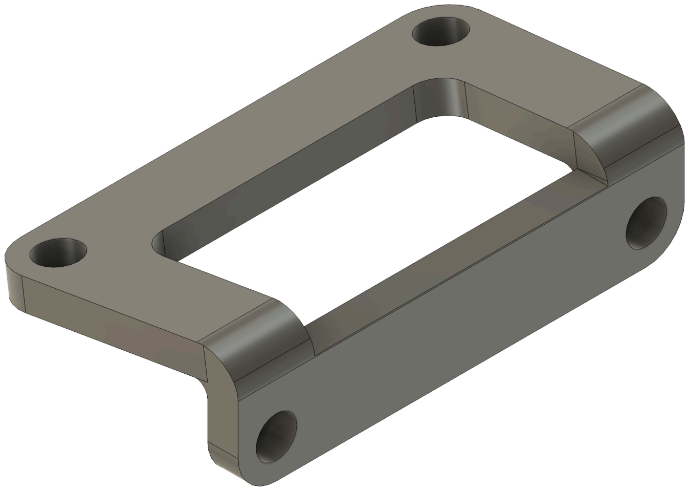
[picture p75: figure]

A simple fixed-angle bracket designed to mount the camera onto the robot chassis.

### 6.4 Chassis

## K WATERMAR ARK WATERMARK WAT RMARK WATERMARK WATERMA

## ATERMARK WATERMARK WATERMARK WA

## K WATERMARK WATERMARK WATERMARK WATERMA

## ARK WATERMARK WATERMARK WATERMARK WATERMARK WA

## RMARK WATERMARK WATERMARK WATERMARK WATERMARK WATERMA TERMARK WATERMARK WATERMARK WATERMARK WATERMARK WATERMARK

Part | Description | Image

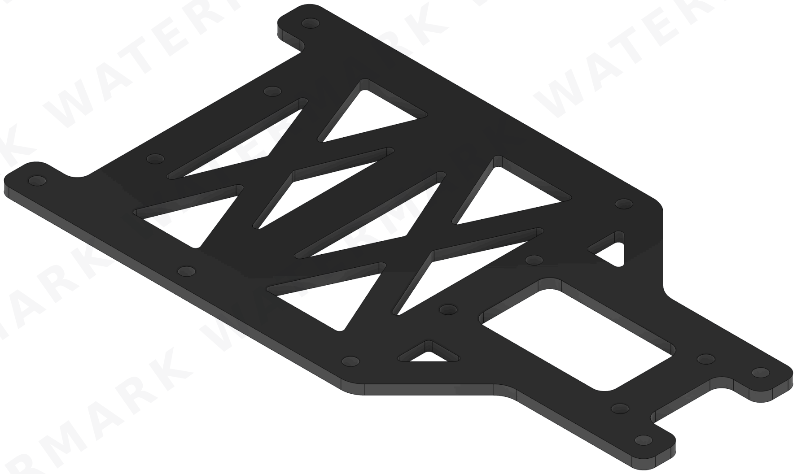
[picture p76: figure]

6.4.1 Chassis Base | The chassis is the robot's main structure, as all other systems are mounted on it. A modular design was chosen to facilitate assembly and maintenance. The chassis is made of stainless steel.

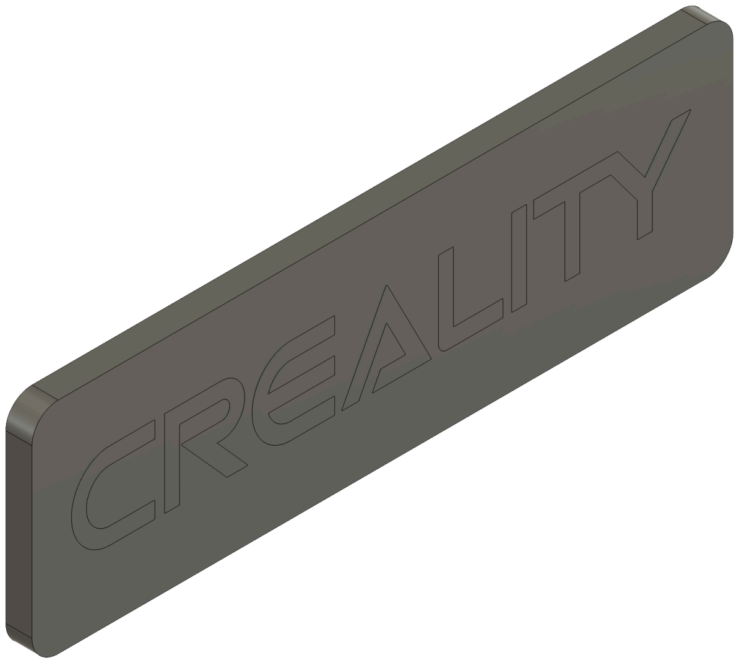
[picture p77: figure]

6.4.2 Front Bumper | Designed for front-end integration, this custom bumper acts as a protective shield for the robot's chassis by absorbing direct frontal impacts and preventing damage to internal electronics or sensors during navigation.

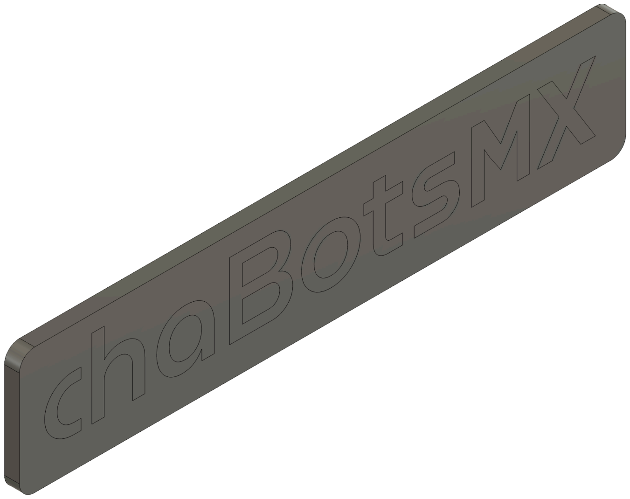
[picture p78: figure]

6.4.3 Rear Bumper | Designed for rear-end protection, this custom bumper shields the back of the chassis and internal components from impacts during reversing maneuvers or wall contact.

### 6.5 Assembly

## K WATERMAR ARK WATERMARK WAT RMARK WATERMARK WATERMA

## ATERMARK WATERMARK WATERMARK WA

## K WATERMARK WATERMARK WATERMARK WATERMA

## ARK WATERMARK WATERMARK WATERMARK WATERMARK WA

## RMARK WATERMARK WATERMARK WATERMARK WATERMARK WATERMA TERMARK WATERMARK WATERMARK WATERMARK WATERMARK WATERMARK

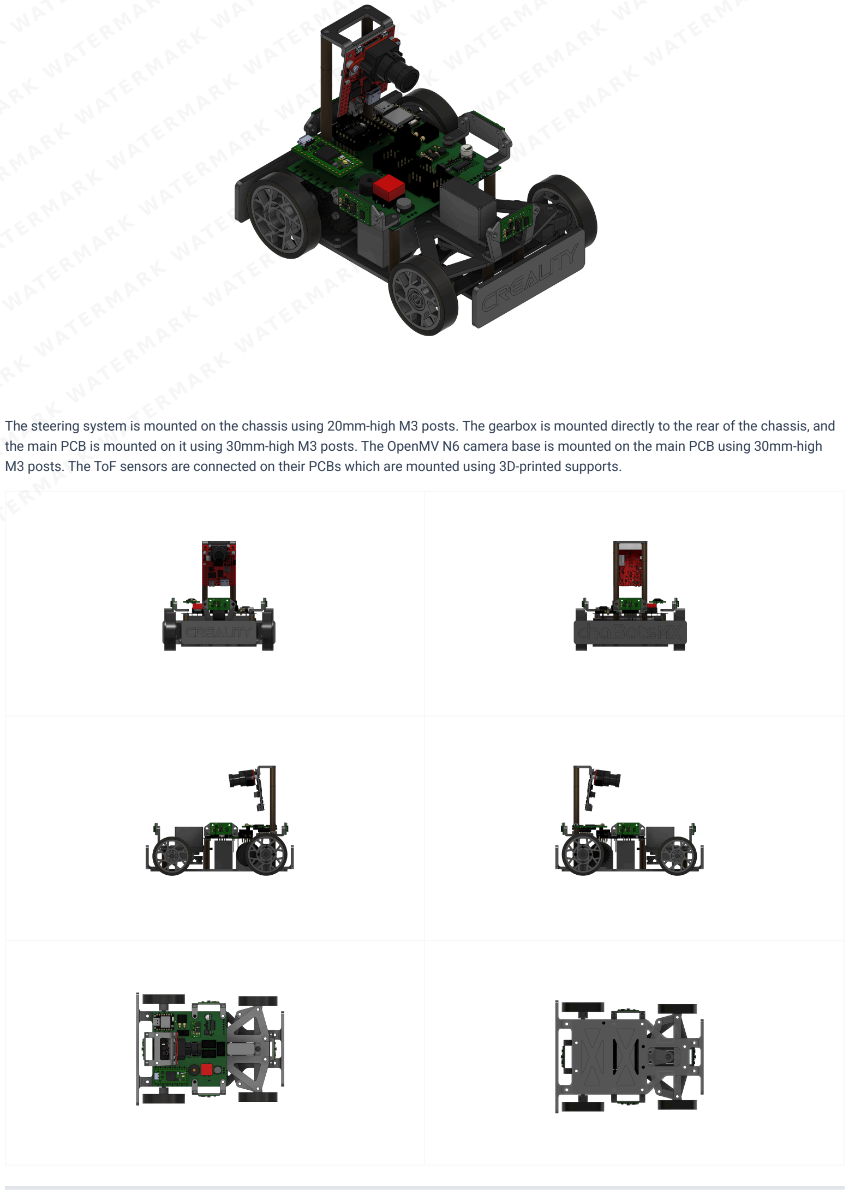
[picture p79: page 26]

The steering system is mounted on the chassis using 20mm-high M3 posts. The gearbox is mounted directly to the rear of the chassis, and the main PCB is mounted on it using 30mm-high M3 posts. The OpenMV N6 camera base is mounted on the main PCB using 30mm-high M3 posts. The ToF sensors are connected on their PCBs which are mounted using 3D-printed supports.

## K WATERMAR ARK WATERMARK WAT RMARK WATERMARK WATERMA

## ATERMARK WATERMARK WATERMARK WA

## K WATERMARK WATERMARK WATERMARK WATERMA

## ARK WATERMARK WATERMARK WATERMARK WATERMARK WA

## RMARK WATERMARK WATERMARK WATERMARK WATERMARK WATERMA TERMARK WATERMARK WATERMARK WATERMARK WATERMARK WATERMARK

## 7. Power, Electronics and Sensor Management

This section describes the hardware that is installed in the final robot and how it is connected. The alternatives, environmental tests, and reasons behind each sensor choice are documented once in Section 4.3: Sensor Changes.

### System Responsibilities

Device | Final role | Main connection
Teensy 4.0 | Main control, state machine, direct ToF acquisition, steering, motor control, encoder processing, and safety logic | SPI, UART, PWM, digital I/O
Seeed Studio XIAO ESP32-C6 | Development telemetry bridge | UART from Teensy; Wi-Fi only during development
OpenMV N6 | Detects red and green obstacles and blue-line references | UART to Teensy
BNO085 | Provides rotation-vector heading for turns and heading correction | UART to Teensy
Pololu #3203 encoder | Measures wheel motion for distance and speed estimation | Quadrature digital inputs
VNH7070AS | Drives the rear DC motor | PWM and direction signals
HiTEC HS-85MG | Controls the Ackermann steering mechanism | Servo PWM

The XIAO can transmit telemetry during development. Wireless functions are disabled during official runs; the competition system does not depend on an external computer or network.

### Competition Configuration

Subsystem | Competition configuration | Firmware or setting
Main controller | Teensy 4.0 | src/src/open-main.cpp for Open; src/src/obstacles-main.cpp for Obstacles
Distance sensing | Four VL53L8CX sensors connected to the Teensy SPI interface | src/lib/TOF4Walls/ ; 60 Hz initialization target
Vision | OpenMV N6 | Obstacle/blue-line packet to Serial3 at 115200 baud
Heading | BNO085 | Rotation-vector yaw to Serial4 at 115200 baud
Motion feedback | Pololu #3203 quadrature encoder | Quadrature inputs processed by src/lib/Move/
Drive | Pololu #3203, 20.4:1 HP 12 V, 500 RPM no-load, through VNH7070AS | PWM and direction from Teensy
Steering | HiTEC HS-85MG and Ackermann linkage | Servo PWM with calibrated map; command limited to ±25.94°
Battery | 3S LiPo, 11.1 V nominal, 1000 mAh | Battery rail for motor; regulated 5 V and 3.3 V rails
Development telemetry | Seeed Studio XIAO ESP32-C6 | src/src/xiao-main.cpp ; not required for an official run

### Firmware Build and Upload

Use PlatformIO from the repository's src/ project directory, which contains the active platformio.ini . Each target compiles one firmware image; only the Open or Obstacles firmware is loaded on the Teensy for a given run.

# Open challenge firmware — Teensy 4.0

pio run -e teensy40

## K WATERMAR ARK WATERMARK WAT RMARK WATERMARK WATERMA

## ATERMARK WATERMARK WATERMARK WA

## K WATERMARK WATERMARK WATERMARK WATERMA

## ARK WATERMARK WATERMARK WATERMARK WATERMARK WA

## RMARK WATERMARK WATERMARK WATERMARK WATERMARK WATERMA TERMARK WATERMARK WATERMARK WATERMARK WATERMARK WATERMARK

# Obstacles challenge firmware — Teensy 4.0 pio run -e teensy40_obstacles

# Development telemetry bridge — XIAO ESP32-C6

pio run -e xiao_esp32c6

To upload a selected target, append -t upload to its command. The OpenMV program is deployed separately with the OpenMV IDE; confirm that its serial packet format matches the active Teensy firmware before the run.

### Power Architecture and Consumption

The robot uses a 3S LiPo battery with a nominal voltage of 11.1 V. The electrical system is divided into three main power rails:

1. Battery rail — 11.1 V nominal: motor driver and drive motor.
2. Regulated 5 V rail: Teensy, XIAO ESP32-C6, OpenMV camera, RGB LED, encoders, and steering servo.
3. Regulated 3.3 V rail: four VL53L8CX ToF sensor modules.

The BNO085 IMU is powered from the Teensy's 3.3 V output and is therefore not connected to the external 3.3 V regulator.

Power is expressed in watts:

Energy stored in the battery is expressed in watt-hours:

For the 11.1 V, 1000 mAh battery:

Component Power Budget

Load | Supply | Normal or design current | Peak current used for design | Peak power | Basis
Teensy 4.0 | 5 V | 100 mA | 100 mA | 0.50 W | Manufacturer operating figure at 600 MHz
XIAO ESP32-C6 | 5 V | 250 mA | 250 mA | 1.25 W | Conservative rail-allocation value; Wi-Fi is disabled during official operation
WS2812B RGB LED | 5 V | 25 mA | 25 mA | 0.125 W | Configured-brightness design value; full-white current can be higher
OpenMV N6 | 5 V | 150 mA | 150 mA | 0.75 W | Full-power value from the OpenMV N6 specification
HS-85MG steering servo | 5 V | 240 mA | 1.2 A | 6.00 W | Published running current plus a conservative transient allowance; 1.2 A is not presented as a measured stall current
Four VL53L8CX carrier boards | 3.3 V | 400 mA total | 600 mA total | 1.98 W | Conservative carrier-board allocation of 100 mA typical and 150 mA peak per module
BNO085 IMU | Teensy 3.3 V output | 12.5 mA | 12.5 mA | 0.041 W | Manufacturer operating figure; excluded from the external 3.3 V rail total
Pololu #3203, 20.4:1 HP 12 V motor | Battery rail | 300 mA no-load | 1.5 A design operating current | 16.65 W at 11.1 V | Manufacturer no-load and approximately 5 A stall figures; 1.5 A is the conservative operating design point

P = V × I

E = V × QAh

### E = 11.1 V × 1 Ah = 11.1Wh

## K WATERMAR ARK WATERMARK WAT RMARK WATERMARK WATERMA

## ATERMARK WATERMARK WATERMARK WA

## K WATERMARK WATERMARK WATERMARK WATERMA

## ARK WATERMARK WATERMARK WATERMARK WATERMARK WA

## RMARK WATERMARK WATERMARK WATERMARK WATERMARK WATERMA TERMARK WATERMARK WATERMARK WATERMARK WATERMARK WATERMARK

The motor's 1.5 A value is the expected high-load operating current used for the main power estimate. It must not be confused with the approximately 5 A stall current, which is treated separately as a short-duration transient.

### 5 V Rail

The normal estimated current, including the servo's published running current, is:

Using the 1.2 A servo transient as the design condition:

A small additional margin is required for the BNO085 because it is powered through the Teensy's onboard 3.3 V regulator. Therefore, the practical 5 V design budget is approximately 1.73 A and 8.7 W.

The 5 V rail uses a Pololu D24V50F5 regulator, rated for approximately 5 A. At a 1.73 A output load, the regulator operates at approximately 35% of its nominal current capacity.

Assuming 90% efficiency:

### 3.3 V ToF Rail

Each VL53L8CX module uses approximately 100 mA during typical continuous ranging and may reach approximately 150 mA.

For four sensors:

For the peak design condition:

The ToF rail uses a Pololu D24V10F3, rated for approximately 1 A. A 600 mA peak load uses 60% of its nominal current capacity.

Assuming 87% efficiency:

### I5V ,normal = 0.100 + 0.250 + 0.025 + 0.150 + 0.240 = 0.765 A

### P5V ,normal = 5 V × 0.765 A = 3.825W

### I5V ,peak = 0.100 + 0.250 + 0.025 + 0.150 + 1.200 = 1.725 A

### P5V ,peak = 5 V × 1.725 A = 8.625W

Pin,5V = | ≈
0.90

8.7W 9.67W

### Ploss,5V = 9.67 − 8.7 ≈ 0.97W

### I3.3V ,typical = 4 × 0.100 = 0.400 A

### P3.3V ,typical = 3.3 V × 0.400 A = 1.32W

### I3.3V ,peak = 4 × 0.150 = 0.600 A

### P3.3V ,peak = 3.3 V × 0.600 A = 1.98W

Pin,3.3V = | ≈
0.87

1.98W 2.28W

### Ploss,3.3V = 2.28 − 1.98 ≈ 0.30W

## K WATERMAR ARK WATERMARK WAT RMARK WATERMARK WATERMA

## ATERMARK WATERMARK WATERMARK WA

## K WATERMARK WATERMARK WATERMARK WATERMA

## ARK WATERMARK WATERMARK WATERMARK WATERMARK WA

## RMARK WATERMARK WATERMARK WATERMARK WATERMARK WATERMA TERMARK WATERMARK WATERMARK WATERMARK WATERMARK WATERMARK

Because the VL53L8CX carrier boards are powered close to their minimum accepted input voltage, the voltage must also be measured directly at the sensor connectors under maximum load to verify that wiring losses do not reduce it excessively.

Motor Rail

The motor is connected to the 3S battery through the VNH7070AS motor driver.

At the selected 1.5 A design operating current and the battery's nominal voltage:

At stall:

Stall is not a normal operating condition, but it must be considered when selecting the battery, motor driver, wiring, connectors, switch, and protection system.

Estimated Total Battery Load

Assuming both regulators are connected directly to the battery:

Section | Output power | Estimated battery input power | Battery current at 11.1 V
5 V regulated rail | 8.7 W | 9.67 W | 0.87 A
3.3 V regulated rail | 1.98 W | 2.28 W | 0.21 A
Motor at design load | 16.65 W | 16.65 W | 1.50 A
Estimated total | — | 28.60 W | 2.58 A

This estimate does not yet include the motor driver's conduction losses, regulator quiescent current, wiring losses, or battery voltage sag. The real battery input will therefore be slightly higher.

With an ideal 11.1 Wh battery:

This value is only a theoretical continuous-load estimate. Real runtime will be lower because of acceleration peaks, steering activity, battery discharge characteristics, voltage sag, and the required safety reserve.

During a motor stall, the complete system could temporarily demand approximately:

Therefore, the 1000 mAh battery must support more than 6.08 A without excessive voltage drop. This corresponds to an absolute theoretical minimum of approximately 6.08C, although a substantially higher battery discharge rating should be used to provide adequate margin.

Power Integrity and Noise Control

Motor and servo current transients can introduce voltage drops and electrical noise into the logic and sensor rails. The PCB therefore uses:

Local decoupling capacitors near each controller and sensor connector.
Bulk capacitance close to the servo and regulator outputs.
Short and wide high-current traces.
Separate high-current return paths for the motor and servo.
Ground pours connected with stitching vias.
A common ground reference between controllers and sensors.
Physical separation between motor-current paths and sensitive sensor signals.
Voltage and current measurements under acceleration, hard steering, and motor-stall test conditions.

### Pmotor = 11.1 V × 1.5 A = 16.65W

### Pmotor,stall = 11.1 V × 5 A = 55.5W

tideal = | =
28.60W

11.1Wh

### 0.388 h ≈ 23.3 minutes

### Istall,total ≈ 5.0 + 0.87 + 0.21 = 6.08 A

## K WATERMAR ARK WATERMARK WAT RMARK WATERMARK WATERMA

## ATERMARK WATERMARK WATERMARK WA

## K WATERMARK WATERMARK WATERMARK WATERMA

## ARK WATERMARK WATERMARK WATERMARK WATERMARK WA

## RMARK WATERMARK WATERMARK WATERMARK WATERMARK WATERMA TERMARK WATERMARK WATERMARK WATERMARK WATERMARK WATERMARK

Theoretical Operating Checks

Test condition | Battery voltage | Battery current | 5 V rail | 3.3 V rail | Expected behavior / acceptance criterion
Electronics idle | ~11.1 V | ~0.15 A | ~0.20 A | ~0.02 A | Rails remain stable and no component heats abnormally
Sensors and camera active | ~11.1 V | ~0.40 A | ~0.43 A | ~0.40 A | Sensor streams remain continuous without controller resets
Motor running straight | ~11.0 V | ~1.20 A | ~0.43 A | ~0.40 A | Motor driver remains within its safe operating temperature
Maximum steering movement | ~11.0 V | ~1.50 A peak | ~1.75 A peak | ~0.40 A | The 5 V rail remains regulated during the servo transient
Acceleration from rest | ~10.8 V | ~3.50 A peak | ~0.43 A | ~0.40 A | The 3.3 V sensor rail remains stable despite motor noise
Brief controlled motor stall | ~10.5 V | ~6.10 A peak | ~0.88 A peak | ~0.40 A | Protection operates without PCB or wiring damage; this is not a normal run condition

Component values were taken from the manufacturers' documentation for the Pololu D24V50F5, (https://www.pololu.com/product/2851) Pololu D24V10F3, (https://www.pololu.com/product/2830) Pololu VL53L8CX carrier, (https://www.pololu.com/product/3419) Teensy 4.0, (https://www.pjrc.com/store/teensy40.html) OpenMV N6, (https://openmv.io/products/openmv-n6) HiTEC HS-85MG, (https://www.hiteccs.com/actuators/product-details/HS-85MG) and Pololu 25D HP motor. (https://www.pololu.com/product/3203/resources) Conservative or assumed values are identified in the table and will be replaced by measurements from the assembled robot.

### Main PCB

A single two-layer PCB integrates the Teensy 4.0, XIAO ESP32-C6, VNH7070AS driver, servo control, power input, feedback devices, and sensor connectors. Its 8 × 8 cm size fits the reduced chassis and replaces the multiple-board arrangement used in the previous robot.

The board is mounted at the top of the chassis. This shortens wiring and makes the electronics accessible without disassembling the drivetrain.

The board uses an XT30 battery connector and includes the main
controller interfaces, motor and servo outputs, sensor headers, and protection components. Ground pours on both layers, stitching vias, short return paths, and careful placement allow reliable high-baud-rate communication even with the motor close to the electronics.

Main robot PCB

### Schematic Overview

The Electronics directory contains the editable Altium projects, schematic PDFs, PCB layouts, STEP models, and Gerber archives for the main board and the camera and ToF interface boards.

Board | Schematic PDFs | Editable project and PCB layout | Manufacturing files | 3D model
Main PCB and motor driver | Main schematic (https://github.com/chaBotsMX/chaBots-Tuneados-WRO-Future-Engineers-2026/blob/main/Electronics/main-pcb/WRO-MAIN.pdf) · H-bridge schematic (https://github.com/chaBotsMX/chaBots-Tuneados-WRO-Future-Engineers-2026/blob/main/Electronics/main-pcb/H-BRIDGE-SCH.pdf) | Altium project · PCB layout | Gerber archive | STEP
Camera interface PCB | Camera schematic (https://github.com/chaBotsMX/chaBots-Tuneados-WRO-Future-Engineers-2026/blob/main/Electronics/cam-pcb/CAM-SCH.pdf) | Altium project · PCB layout | Gerber archive | STEP
ToF interface PCB | ToF schematic (https://github.com/chaBotsMX/chaBots-Tuneados-WRO-Future-Engineers-2026/blob/main/Electronics/tof-pcb/TOF-SCH.pdf) | Altium project · PCB layout | Gerber archive | STEP

The PDFs provide readable circuit references without requiring a PCB editor. Each board folder also includes editable .SchDoc schematic files and PNG previews. Open the .PrjPcb project in Altium Designer to work with its schematic and layout; extract the .rar archive to access the supplied Gerber files. The STEP models support mechanical integration with the chassis and mounts.

Complete PCB schematic

## K WATERMAR ARK WATERMARK WAT RMARK WATERMARK WATERMA

## ATERMARK WATERMARK WATERMARK WA

## K WATERMARK WATERMARK WATERMARK WATERMA

## ARK WATERMARK WATERMARK WATERMARK WATERMARK WA

RMARK (https://www.pjrc.com/store/teensy40.html) WATERMARK WATERMARK WATERMARK WATERMARK WATERMA

## TERMARK WATERMARK WATERMARK WATERMARK WATERMARK WATERMARK

Microcontrollers

Microcontroller schematic

Logic connections for the Teensy 4.0 and Seeed Studio XIAO ESP32-C6.

Power Delivery

Power-delivery schematic

XT30 battery connector, 6 A slide switch, Pololu D24V50F5 5 V regulator, Pololu D24V10F3 3.3 V regulator, filtered servo output, and motor output.

Debugging and Feedback

Debugging schematic

Buzzer, power LED, start button, and programmable RGB LED.

Sensors

Sensor schematic

IDC connections for the ToF boards, UART camera connection, and the BNO085 mounted directly on the PCB.

### BNO085 IMU

The BNO085 replaced the BNO055. We use its rotation-vector output over UART because it produced lower drift and required less repeated calibration in our tests. The dedicated serial link keeps heading traffic separate from the SPI ToF acquisition and gives the Teensy a direct heading stream. The comparison and environmental reasoning are in Section 4.3.3.

### Teensy 4.0

Role: main real-time controller for navigation, PWM generation, encoder processing, sensor timing, and safety interlocks.
Power integrity: local 0.1 µF decoupling and a 10 µF bulk capacitor are placed close to the controller supply.
I/O: SPI acquires all four VL53L8CX streams directly; UART receives the BNO085 and OpenMV N6 data; quadrature inputs read the motor encoder; dedicated PWM and direction lines drive the VNH7070AS and steering servo.
Signal integrity: short digital runs and optional 33–100 Ω series resistors reduce ringing on fast control signals.

### VNH7070AS Motor-Driver Stage

The VNH7070AS full bridge is integrated directly into the PCB because a suitable compact module was not available. It provides the current capacity needed by the rear motor while leaving voltage and thermal headroom.

Interface: direction, PWM, enable, current-sense, and fault signals connect to the Teensy.
Decoupling: bulk capacitance is placed beside the driver, with local 100 nF ceramic capacitors and a TVS device on the motor supply. EMI control: motor leads are kept short and twisted; an RC snubber can be fitted if testing shows excessive brush noise.
Thermal path: a copper area and thermal vias spread heat from the exposed pad.

### Connectors and Peripherals

The servo header is supplied from the regulated 5 V rail with its return path routed beside the supply trace. IDC connectors make the four ToF boards removable and reduce wiring mistakes.
Dedicated headers expose the OpenMV UART, BNO085 UART, and ToF SPI connections for diagnosis. The buzzer, status LEDs, RGB LED, and start button provide feedback without an external display.
The OpenMV N6 can be calibrated and inspected through USB-C and the OpenMV IDE.

## 8. Software Architecture and Control

The robot’s code was completely remade from last year. This change was necessary because the system architecture is now different, but also because last year’s software was not as well structured as we wanted.

## K WATERMAR ARK WATERMARK WAT RMARK WATERMARK WATERMA

## ATERMARK WATERMARK WATERMARK WA

## K WATERMARK WATERMARK WATERMARK WATERMA

## ARK WATERMARK WATERMARK WATERMARK WATERMARK WA

## RMARK WATERMARK WATERMARK WATERMARK WATERMARK WATERMA TERMARK WATERMARK WATERMARK WATERMARK WATERMARK WATERMARK

Last year, the robot used a Raspberry Pi as the main processing unit, while the Teensy 4.0 worked mostly as a low-level slave for motor control. This year, we moved to a simpler and more deterministic architecture. The Teensy 4.0 is now the main controller, while the Seeed Studio XIAO ESP32-C6 is used only for wireless debugging during development.

For this year’s code, we are focusing on improving every aspect of the software, especially:

Better code structure

More reliable sensor communication

Cleaner libraries

More consistent variable names

Easier debugging

Better separation between sensing, control, and actuation

The current release candidate implements both competition modes through shared sensing, motion, steering, and safety modules. Remaining work is tracked as field validation and tuning rather than as a second software architecture.

### 8.1 Seeed Studio XIAO ESP32-C6

The XIAO ESP32-C6 is a development-only telemetry bridge in the current repository. Its firmware ( src/src/xiao-main.cpp ) validates fixed telemetry frames received from the Teensy over UART and publishes the latest valid frame to the debugging application over Wi-Fi.

The XIAO is not part of the control loop for an official run: it does not acquire ToF data, generate steering commands, or drive the motor. Official operation remains autonomous on the Teensy, with wireless telemetry disabled.

### 8.2 Teensy 4.0

The Teensy 4.0 is the real-time controller for both competition modes. It initializes the BNO085 and four VL53L8CX sensors, reads OpenMV packets, processes encoder feedback, controls the VNH7070AS drive stage and steering servo, and executes the selected state machine.

The two entry points are | src/src/open-main.cpp | and | src/src/obstacles-main.cpp . Both share the | Robot | facade and the sensor, motion, trajectory,
and Ackermann libraries under | src/lib/ ; their loop calls select the Open or Obstacles state machine.

### 8.2.1 Direct ToF Acquisition and Startup

The current firmware initializes the four VL53L8CX sensors directly from the Teensy SPI interface through TOF4Walls . It uses one front, rear, left, and right measurement stream; the navigation layer receives normalized millimeter values.

A new reading is valid only when it is non-negative, below 3000 mm, and no older than the configured 50 ms sensor timeout. Invalid or stale readings are replaced by an invalid sentinel before wall-following or obstacle logic uses them.

Startup proceeds in this order:

1. Initialize serial ports and the motor interface.
2. Initialize the BNO085; on failure, the Teensy performs a controlled software reset.
3. Initialize the four VL53L8CX sensors at the configured 60 Hz; on failure, the Teensy performs a controlled software reset.
4. Initialize the user interface and steering actuator, then wait for the start button while fresh sensor activity is shown locally.
5. Capture the initial heading as the IMU setpoint and enter the selected state machine.

The camera is not a startup interlock in the current firmware. If no fresh camera packet is available during the Obstacles mode, the controller continues its non-vision behavior; this is recorded as a known limitation in Section 10.

### 8.2.1.1 Pre-Competition Calibration

Perform these checks in order before a documented run:

1. Steering center — every assembly: Command the neutral steering position, attach the linkage without preload, and confirm both wheels are centered and clear the chassis through their full travel.

## K WATERMAR ARK WATERMARK WAT RMARK WATERMARK WATERMA

## ATERMARK WATERMARK WATERMARK WA

## K WATERMARK WATERMARK WATERMARK WATERMA

## ARK WATERMARK WATERMARK WATERMARK WATERMARK WA

## RMARK WATERMARK WATERMARK WATERMARK WATERMARK WATERMA TERMARK WATERMARK WATERMARK WATERMARK WATERMARK WATERMARK

2. BNO085 heading — every power cycle: Keep the vehicle stationary during initialization, then set the current yaw as the reference heading immediately before the start button is pressed.
3. Encoder scale — after any wheel, tire, gearbox, or encoder change: Compare commanded travel with measured straight-line travel and update the distance-per-count calibration only after recording the error.
4. ToF array — every setup: Confirm front, rear, left, and right readings are fresh and plausible at a known wall distance; inspect the mounting direction after transporting the robot.
5. OpenMV N6 — every lighting change: Load the competition vision program, set the experimental white-balance control and color thresholds, verify the region of interest, and confirm the required obstacle and blue-line packets over UART.
6. Wall reference and evasion — every field change: Verify the selected wall distance, side-wall protection threshold, and tangential-image parameters with low-speed passes before full-speed runs.

The mechanical steering map is retained between runs unless the linkage is disturbed. Encoder scale is retained only while the wheel and drivetrain configuration remain unchanged.
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

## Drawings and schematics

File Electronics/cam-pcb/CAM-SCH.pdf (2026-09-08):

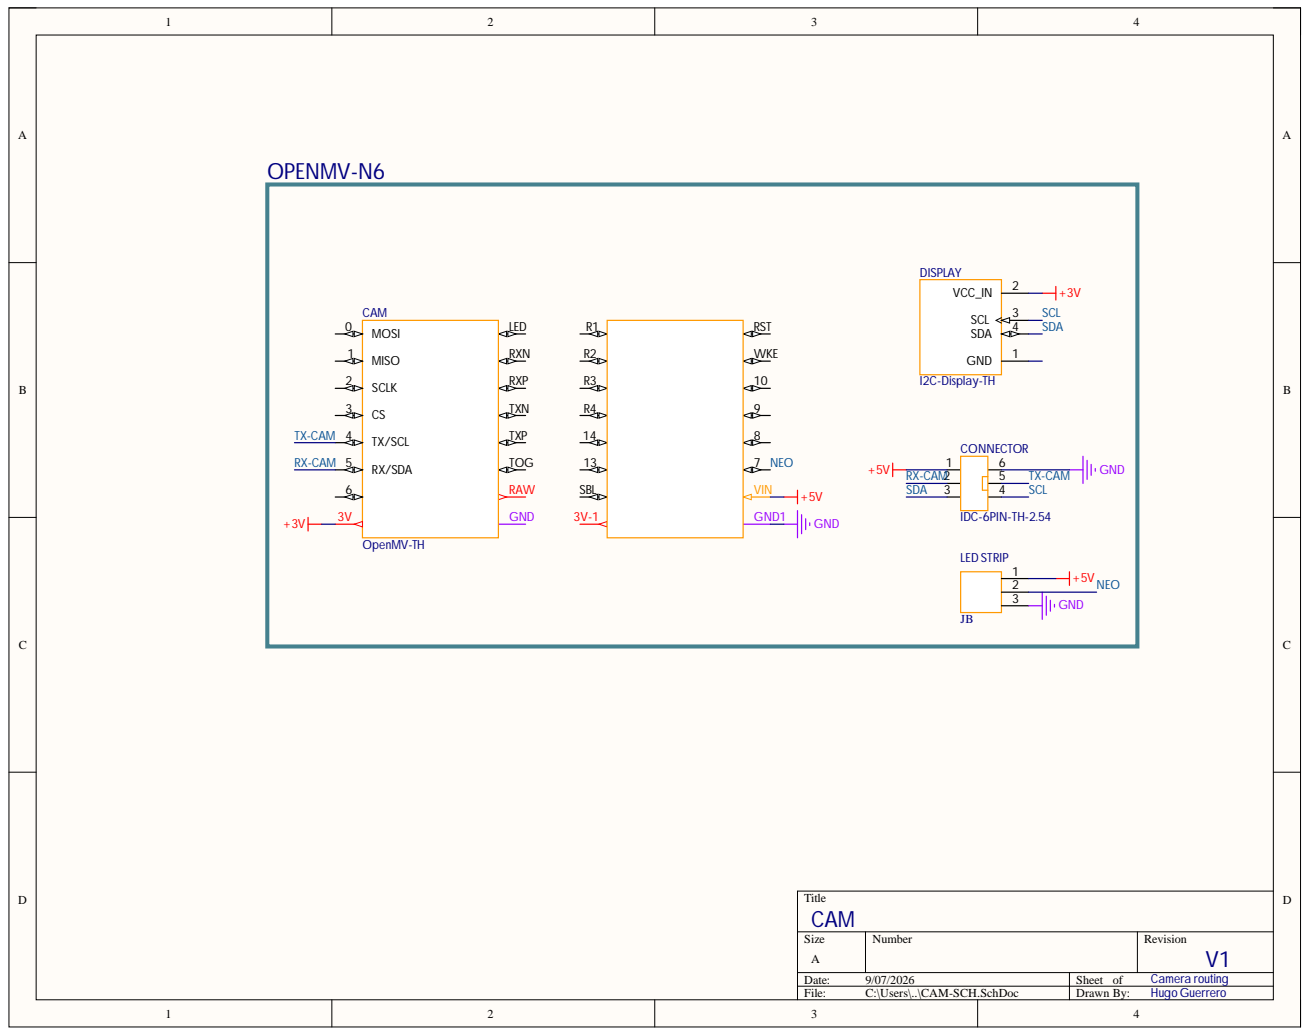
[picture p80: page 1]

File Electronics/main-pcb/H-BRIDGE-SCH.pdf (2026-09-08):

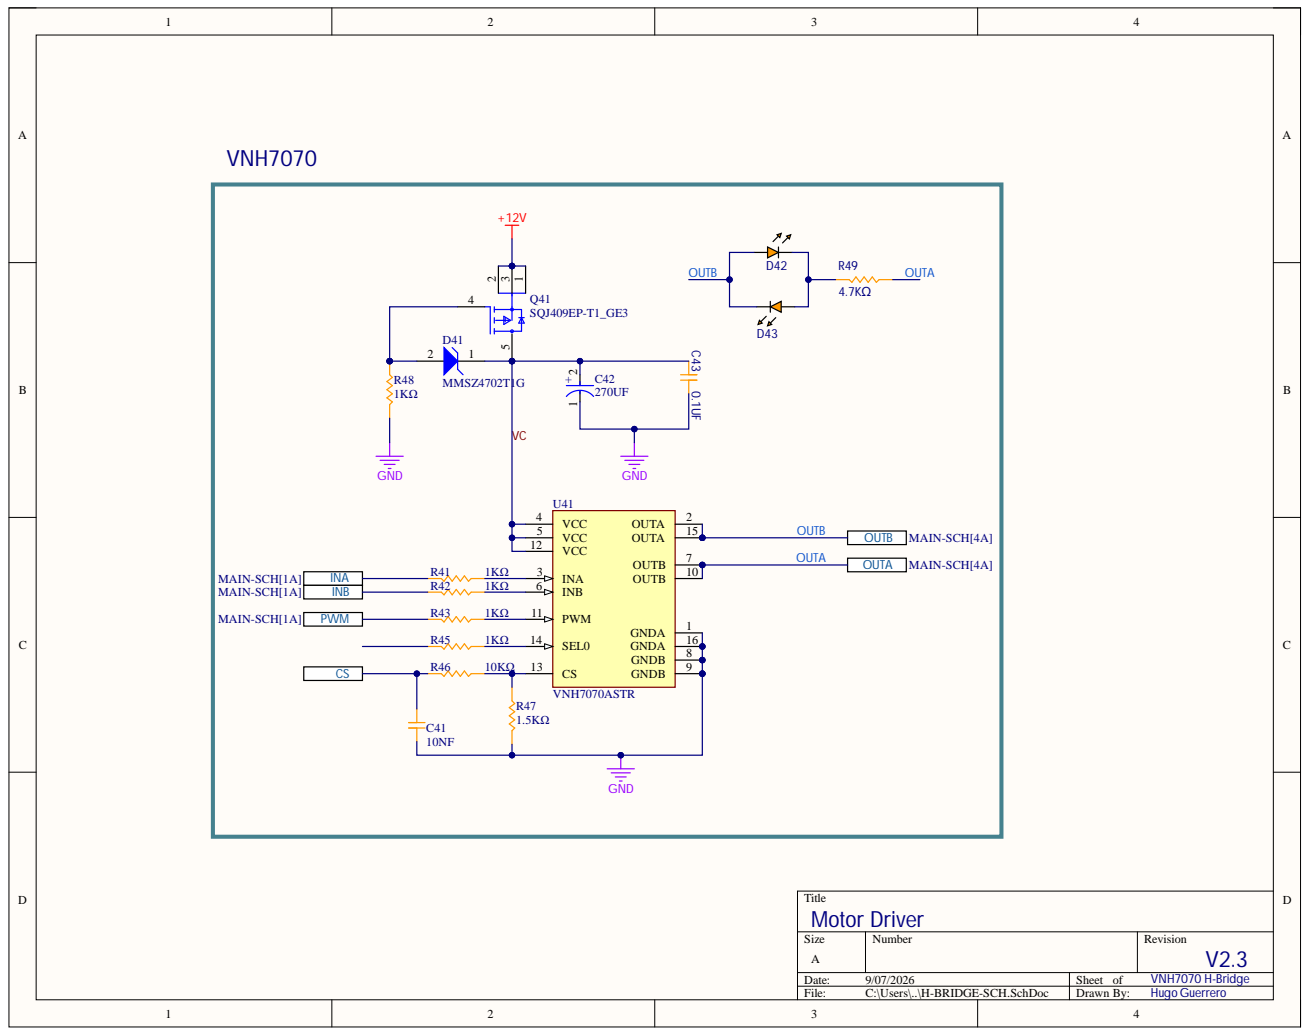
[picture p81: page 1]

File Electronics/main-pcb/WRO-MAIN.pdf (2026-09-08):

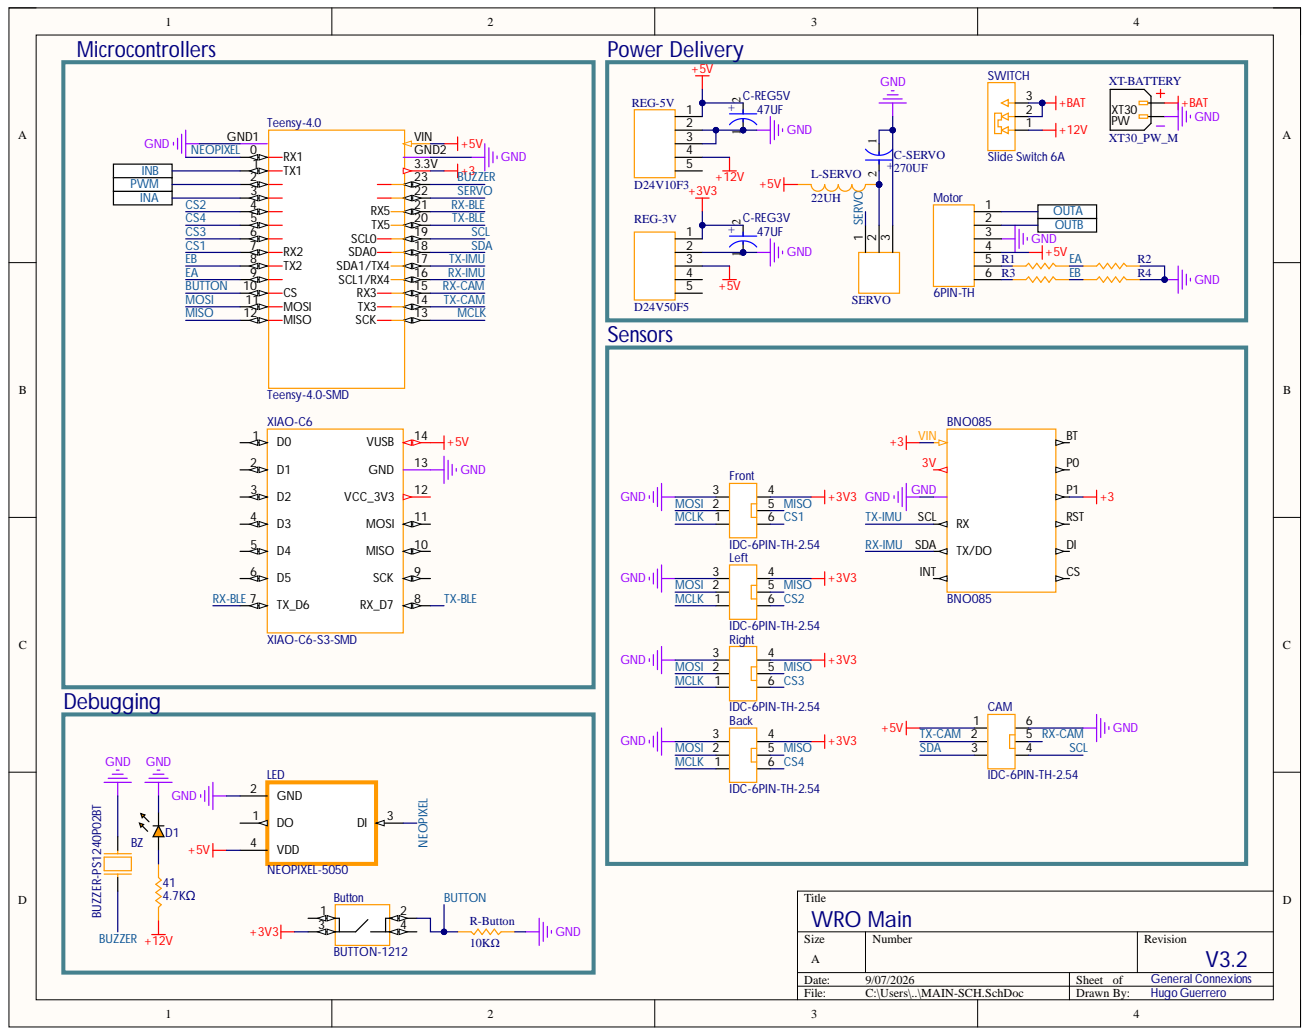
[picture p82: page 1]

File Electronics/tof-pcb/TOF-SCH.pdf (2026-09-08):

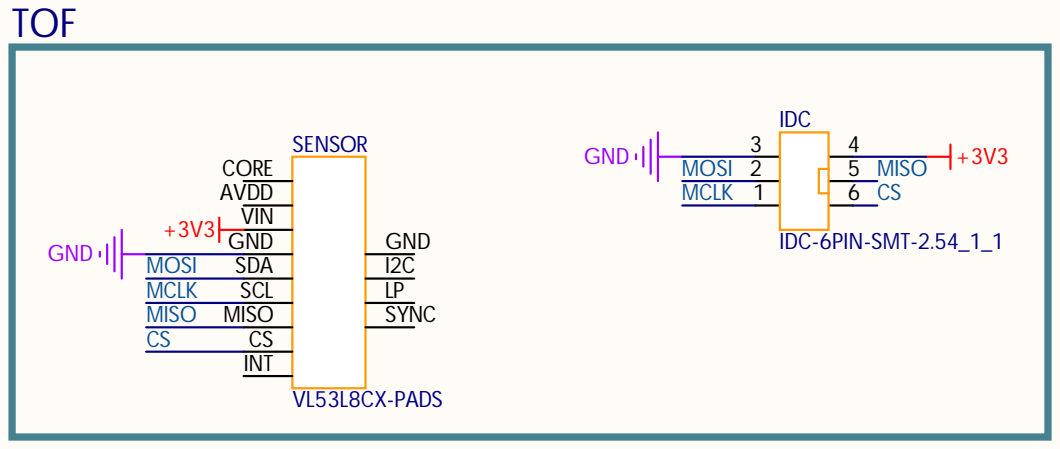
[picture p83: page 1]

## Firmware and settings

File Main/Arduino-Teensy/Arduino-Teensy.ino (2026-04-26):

#include <Adafruit_NeoPixel.h>
#include "IMU.h"
#include <Servo.h>
#include <Encoder.h>

#define BUTTON      10
#define BUZZER      11
#define SERVOMOTOR  12
#define INA         3
#define INB         1
#define PWM         2
#define ENCA        9
#define ENCB        8

#define CPRPERSHAFTREVOLUTION 979.6128f
#define MAXRPS 8.3333f
#define DISTANCEPERREVOLUTION 13.037f   // cm
const float MM_PER_TICK = (DISTANCEPERREVOLUTION * 10.0f) / CPRPERSHAFTREVOLUTION;

int butState = 0;

Servo servo;
IMU imu;
Encoder motorEnc(ENCA, ENCB);
Adafruit_NeoPixel pixels(1, 22, NEO_GRB + NEO_KHZ800);

int setPointWall = 300;     // mm a la pared seguida
int setPointIMU  = 0;       // heading deseado en rango -180..180

const int servoCenter = 90;

// Ganancias
float kpWall = 0.25f;
float kpIMU  = 0.55f;
float kpTurn = 1.50f;

float kdWall = 0.15f;
float kdIMU  = 0.25f;

float lastErrorIMU  = 0.0f;
float lastErrorWall = 0.0f;

elapsedMillis lastReadWall;
elapsedMillis lastReadIMU;

// Límites servo
const int servoMin = 60;
const int servoMax = 120;

// Umbrales
const int frontTurnThreshold = 600;   // mm para comenzar giro
const int turnFinishError    = 10;    // grados tolerancia de fin de giro

// Validación pared
const int wallMinValid = 0;
const int wallMaxValid = 2000;
const int maxWallError = 300;

elapsedMillis finalTimer;
bool finalAdvanceStarted = false;

// Filtro de salto de pared.
// Antes de saber el sentido, si la pared seguida brinca mucho,
// se ignora la pared y se usa solo IMU.
const int WALL_JUMP_THRESHOLD_MM = 1000;
uint16_t lastWallDistForJump = 0;
bool lastWallDistValidForJump = false;

// Velocidades máximas
const int maxPWM = 130;
const int minPWM = 70;

// Filtro de TOF
const uint16_t TOF_MAX_VALID_MM = 3000;

// Distancias estimadas continuas
float estFront = 0.0f;
float estLeft  = 0.0f;
float estRight = 0.0f;
bool distInitialized = false;

uint16_t front = 1500, left = 0, right = 0;
bool finish = 0;
bool turning = false;
bool turnArmed = true;
int errorIMU = 0;
int outError = 0;
const int rP = 4;
int turnCount = 0;

// Selección automática de sentido
bool directionChosen = false;
bool choosingDirection = false;
elapsedMillis directionChoiceTimer;

const uint32_t DIRECTION_CHOICE_WAIT_MS = 1000;

// +1 = antihorario, gira izquierda, sigue pared derecha
// -1 = horario, gira derecha, sigue pared izquierda
int turnDirection = 1;

int wrap180(int ang) {
    while (ang > 180)  ang -= 360;
    while (ang <= -180) ang += 360;
    return ang;
}

int angleErrorDeg(int target, int current) {
    return wrap180(target - current);
}

int32_t getEncoderTicks() {
    return motorEnc.read();
}

void motorForwardPWM(int pwm) {
    digitalWrite(INA, LOW);
    digitalWrite(INB, HIGH);
    analogWrite(PWM, constrain(pwm, 0, 255));
}

void motorStop() {
    digitalWrite(INA, LOW);
    digitalWrite(INB, LOW);
    analogWrite(PWM, 0);
}

void resetWallJumpFilter() {
    lastWallDistForJump = 0;
    lastWallDistValidForJump = false;
}

void syncEstimateFromCurrentDistances() {
    estFront = (float)front;
    estLeft  = (float)left;
    estRight = (float)right;
    distInitialized = true;
}

void publishEstimatedDistances() {
    front = (uint16_t)constrain((int)estFront, 0, (int)TOF_MAX_VALID_MM);
    left  = (uint16_t)constrain((int)estLeft,  0, (int)TOF_MAX_VALID_MM);
    right = (uint16_t)constrain((int)estRight, 0, (int)TOF_MAX_VALID_MM);
}

void updateEstimatedDistances(int yaw) {
    static int32_t lastTicks = 0;

    int32_t ticks = getEncoderTicks();
    int32_t deltaTicks = ticks - lastTicks;
    lastTicks = ticks;

    if (!distInitialized || deltaTicks == 0) return;

    float ds = (float)deltaTicks * MM_PER_TICK;

    // Si el signo sale invertido en la práctica, cambia ds por -ds
    float alpha = radians((float)wrap180(yaw - setPointIMU));

    float dForward = ds * cos(alpha);
    float dLeft    = ds * sin(alpha);

    estFront -= dForward;
    estRight += dLeft;
    estLeft  -= dLeft;

    estFront = constrain(estFront, 0.0f, (float)TOF_MAX_VALID_MM);
    estLeft  = constrain(estLeft,  0.0f, (float)TOF_MAX_VALID_MM);
    estRight = constrain(estRight, 0.0f, (float)TOF_MAX_VALID_MM);
}

bool readTOFPacket(HardwareSerial &port, uint16_t &front, uint16_t &left, uint16_t &right) {
    static uint8_t state = 0;
    static uint8_t buffer[6];
    static uint8_t index = 0;

    while (port.available()) {
        uint8_t c = port.read();

        switch (state) {
            case 0:
                if (c == 0xAA) {
                    index = 0;
                    state = 1;
                }
                break;

            case 1:
                buffer[index++] = c;
                if (index >= 6) {
                    uint16_t newFront = (uint16_t)buffer[0] | ((uint16_t)buffer[1] << 8);
                    uint16_t newLeft  = (uint16_t)buffer[2] | ((uint16_t)buffer[3] << 8);
                    uint16_t newRight = (uint16_t)buffer[4] | ((uint16_t)buffer[5] << 8);

                    // Si una lectura pasa de 3000 mm, se descarta y se conserva la anterior
                    if (newFront <= TOF_MAX_VALID_MM) front = newFront;
                    if (newLeft  <= TOF_MAX_VALID_MM) left  = newLeft;
                    if (newRight <= TOF_MAX_VALID_MM) right = newRight;

                    state = 0;
                    return true;
                }
                break;
        }
    }

    return false;
}

bool followingLeftWall() {
    return directionChosen && turnDirection == -1;
}

uint16_t getFollowWallDistance() {
    if (followingLeftWall()) {
        return left;
    }

    return right;
}

int getWallServoSign() {
    // Pared derecha:
    // Si está lejos de la pared derecha, errorWall positivo debe mandar servo hacia la derecha.
    // En este robot eso corresponde a restar wallTerm.
    //
    // Pared izquierda:
    // Si está lejos de la pared izquierda, errorWall positivo debe mandar servo hacia la izquierda.
    // En este robot eso corresponde a sumar wallTerm.
    if (followingLeftWall()) {
        return +1;
    }

    return -1;
}

bool wallDistanceAllowedForSteering(uint16_t wallDist) {
    // Caso especial antes de saber el sentido.
    // Al inicio se sigue la derecha. Si en realidad el sentido correcto era horario,
    // puede perder esa pared y brincar de ~200 a valores grandes.
    // En ese caso se usa solo IMU para evitar un giro brusco.
    if (!directionChosen) {
        if (lastWallDistValidForJump) {
            int jump = abs((int)wallDist - (int)lastWallDistForJump);

            if (jump > WALL_JUMP_THRESHOLD_MM) {
                return false;
            }
        }

        // Solo actualizamos la referencia si la lectura parece usable.
        if (wallDist >= wallMinValid && wallDist <= wallMaxValid) {
            lastWallDistForJump = wallDist;
            lastWallDistValidForJump = true;
        }
    }

    if (wallDist < wallMinValid || wallDist > wallMaxValid) {
        return false;
    }

    return true;
}

void updateSteering(int yaw) {
    errorIMU = angleErrorDeg(setPointIMU, yaw);

    float dtIMU = max(1.0f, (float)lastReadIMU);
    float dErrIMU = (errorIMU - lastErrorIMU) / dtIMU;
    float imuTerm = kpIMU * errorIMU + kdIMU * dErrIMU;
    lastErrorIMU = errorIMU;
    lastReadIMU = 0;

    float wallTerm = 0.0f;
    uint16_t wallDist = getFollowWallDistance();

    bool useWall = wallDistanceAllowedForSteering(wallDist);

    if (useWall) {
        float limitedAngle = constrain((float)errorIMU, -35.0f, 35.0f);
        float theta = radians(limitedAngle);

        // Distancia perpendicular corregida
        float wallCorrected = (float)wallDist * cos(theta);

        int errorWall = (int)wallCorrected - setPointWall;
        errorWall = constrain(errorWall, -maxWallError, maxWallError);

        float wallWeight = 1.0f - min(abs(errorIMU) / 40.0f, 1.0f);

        float dtWall = max(1.0f, (float)lastReadWall);
        float dErrWall = (errorWall - lastErrorWall) / dtWall;

        wallTerm = wallWeight * (kpWall * errorWall + kdWall * dErrWall);

        lastErrorWall = errorWall;
        lastReadWall = 0;
    } else {
        // Solo IMU.
        // También evitamos que el derivativo de pared guarde un error viejo.
        lastErrorWall = 0.0f;
        lastReadWall = 0;
    }

    int wallServoSign = getWallServoSign();

    if (useWall && wallTerm > 30) {
        int servoCmd = constrain((int)(servoCenter + wallServoSign * wallTerm), servoMin, servoMax);
        outError = abs(90 - servoCmd);
        servo.write(servoCmd);
    }
    else {
        int servoCmd = constrain((int)(servoCenter + imuTerm + wallServoSign * wallTerm), servoMin, servoMax);
        outError = abs(90 - servoCmd);
        servo.write(servoCmd);
    }
}

void startTurnByDirection() {
    setPointIMU = wrap180(setPointIMU + (90 * turnDirection));
    turning = true;
    turnArmed = false;

    resetWallJumpFilter();
}

void startDirectionChoice() {
    choosingDirection = true;
    directionChoiceTimer = 0;
    turnArmed = false;

    motorStop();
    servo.write(servoCenter);

    resetWallJumpFilter();

    tone(BUZZER, 1100, 100);
}

void finishDirectionChoiceAndStartTurn() {
    choosingDirection = false;
    directionChosen = true;

    if (left >= right) {
        turnDirection = 1;   // antihorario: gira izquierda y sigue pared derecha
        tone(BUZZER, 1500, 100);
    } else {
        turnDirection = -1;  // horario: gira derecha y sigue pared izquierda
        tone(BUZZER, 700, 100);
    }

    resetWallJumpFilter();

    startTurnByDirection();
    turnCount++;
}

void updateDirectionChoice() {
    motorStop();
    servo.write(servoCenter);

    if (directionChoiceTimer >= DIRECTION_CHOICE_WAIT_MS) {
        finishDirectionChoiceAndStartTurn();
    }
}

void updateTurn(int yaw) {
    int turnError = angleErrorDeg(setPointIMU, yaw);

    int servoCmd = constrain((int)(servoCenter + kpTurn * turnError), servoMin, servoMax);
    servo.write(servoCmd);

    if (abs(turnError) <= turnFinishError) {
        turning = false;
    }
}

int calcSpeed() {
    if (!turning) {
        int reductionError = outError * rP;
        float disVel = constrain(front / 2000.0f, 0.0f, 1.0f) * 70.0f;
        int outSpeed = 100 + (int)disVel - reductionError;
        return constrain(outSpeed, minPWM, maxPWM);
    } else {
        return 80;
    }
}

void setup() {
    pinMode(INA, OUTPUT);
    pinMode(INB, OUTPUT);
    pinMode(PWM, OUTPUT);

    pinMode(BUTTON, INPUT);
    pinMode(BUZZER, OUTPUT);

    analogWriteFrequency(PWM, 20000);

    Serial.begin(115200);
    Serial4.begin(115200);    // IMU
    Serial5.begin(2000000);   // TOF UART

    pixels.begin();
    pixels.clear();
    pixels.show();

    servo.attach(SERVOMOTOR);
    servo.write(servoCenter);

    imu.begin(Serial4);

    motorEnc.write(0);

    delay(1000);
}

void loop() {
    while (butState == 0) {
        if (digitalRead(BUTTON) == 1) {
            butState = 1;
            tone(BUZZER, 700, 500);
            delay(300);
        }

        bool newTofStart = readTOFPacket(Serial5, front, left, right);
        if (newTofStart) {
            syncEstimateFromCurrentDistances();
            pixels.setPixelColor(0, pixels.Color(50, 50, 50));
        } else {
            pixels.setPixelColor(0, pixels.Color(0, 0, 0));
        }
        pixels.show();
        Serial.println(front);
    }

    imu.update();
    int imuRead = wrap180(imu.getYaw());

    // Primero estimar con encoder + IMU
    updateEstimatedDistances(imuRead);
    if (distInitialized) {
        publishEstimatedDistances();
    }

    // Luego corregir con lectura real si llega
    bool newTof = readTOFPacket(Serial5, front, left, right);
    if (newTof) {
        syncEstimateFromCurrentDistances();
    }

    if (choosingDirection) {
        updateDirectionChoice();

        pixels.setPixelColor(0, pixels.Color(20, 20, 50));
        pixels.show();

        return;
    }

    // Rearmar el giro solo cuando el frente vuelva a estar despejado
    if (front > frontTurnThreshold + 100) {
        turnArmed = true;
    }

    // Motor hacia adelante
    motorForwardPWM(calcSpeed());

    if (finish == 1) {
        motorStop();
    }
    else if (turnCount == 12 && !turning) {
        if (!finalAdvanceStarted) {
            finalTimer = 0;
            finalAdvanceStarted = true;
        }

        if (finalTimer < 1500) {
            updateSteering(imuRead);
            motorForwardPWM(calcSpeed());
        }
        else {
            finish = 1;
        }
    }
    else if (!turning) {
        updateSteering(imuRead);

        if (turnArmed && front < frontTurnThreshold && abs(errorIMU) < 10) {
            if (!directionChosen) {
                startDirectionChoice();
            } else {
                startTurnByDirection();
                turnCount++;
                tone(BUZZER, 1500, 100);
            }
        }
    } else {
        updateTurn(imuRead);
    }

    if (newTof) {
        if (followingLeftWall()) {
            pixels.setPixelColor(0, pixels.Color(50, 0, 50));   // siguiendo izquierda
        } else {
            pixels.setPixelColor(0, pixels.Color(0, 0, 50));    // siguiendo derecha
        }
    } else {
        pixels.setPixelColor(0, pixels.Color(0, 0, 0));
    }

    pixels.show();
}

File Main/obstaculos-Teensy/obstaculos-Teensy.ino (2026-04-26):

#include <Adafruit_NeoPixel.h>
#include "IMU.h"
#include <Servo.h>

#define BUTTON      10
#define BUZZER      11
#define SERVOMOTOR  12
#define INA         3
#define INB         1
#define PWM         2

int butState = 0;

Servo servo;
IMU imu;
Adafruit_NeoPixel pixels(1, 22, NEO_GRB + NEO_KHZ800);

// UARTs usados:
// Serial4 = IMU
// Serial5 = TOF
// Serial3 = OpenMV

// Servo
const int servoCenter = 90;
const int servoMin = 60;
const int servoMax = 120;

int lastServoCmd = servoCenter;
int recoveryServoCmd = servoCenter;

// IMU
int setPointIMU = 0;
int errorIMU = 0;

float kpIMU = 0.95f;
float kdIMU = 0.20f;
float kpTurn = 1.50f;

float lastErrorIMU = 0.0f;
elapsedMillis lastReadIMU;

// Motor
const int normalPWM = 120;
const int turnPWM = 85;
const int reversePWM = 100;

// TOF
const uint16_t TOF_MAX_VALID_MM = 3000;
const int frontTurnThreshold = 600;
const int turnFinishError = 3;

uint16_t front = 1500;
uint16_t left = 0;
uint16_t right = 0;

// Giro / estados
bool finish = false;
bool turning = false;
bool turnArmed = true;
bool reversing = false;

elapsedMillis reverseTimer;
const uint32_t REVERSE_TIME_MS = 3000;

int turnCount = 0;
const int MAX_TURNS = 12;

// Detección automática de sentido
bool directionChosen = false;
bool choosingDirection = false;
elapsedMillis directionChoiceTimer;

const uint32_t DIRECTION_CHOICE_WAIT_MS = 1000;

// +1 = antihorario / izquierda / +90
// -1 = horario / derecha / -90
int turnDirection = 1;

// Confirmación de pared real
elapsedMillis noPillarTimer;
elapsedMillis wallConfirmTimer;

const uint32_t NO_PILLAR_BEFORE_TURN_MS = 350;
const uint32_t WALL_CONFIRM_MS = 120;

// Recuperación corta
bool recovering = false;
bool retryTurnAfterRecovery = false;
elapsedMillis recoveryTimer;

const uint32_t RECOVERY_REVERSE_TIME_MS = 1500; // corregido de 15h00
const uint16_t PILLAR_DANGER_FRONT_MM = 50;

const int RECOVERY_TURN_FINISH_ERROR = turnFinishError + 2;

elapsedMillis turnTimer;
const uint32_t TURN_FAIL_TIME_MS = 1400;

// OpenMV
struct OpenMVBlob {
    uint16_t x = 0;
    uint16_t y = 0;
    uint8_t colorId = 0;
    bool valid = false;
};

OpenMVBlob camBlob;

const int CAM_WIDTH = 320;
const int CAM_CENTER_X = 160;

const float CAM_HALF_FOV_DEG = 30.0f;

const bool CAM_INVERT_X = false;

const uint8_t COLOR_RED = 1;
const uint8_t COLOR_GREEN = 2;

const int PASS_OFFSET_DEG = 30;
const int VISION_DEAD_ZONE_DEG = 20;

const int MAX_VISION_CORRECTION_DEG = 60;
const int CORR_KP = 4;

elapsedMillis lastCamPacket;
const uint32_t CAM_TIMEOUT_MS = 300;

int wrap180(int ang) {
    while (ang > 180) ang -= 360;
    while (ang <= -180) ang += 360;
    return ang;
}

int angleErrorDeg(int target, int current) {
    return wrap180(target - current);
}

void writeServoCmd(int cmd) {
    cmd = constrain(cmd, servoMin, servoMax);
    lastServoCmd = cmd;
    servo.write(cmd);
}

int getInvertedServoCmd() {
    int inverted = (servoCenter * 2) - lastServoCmd;
    return constrain(inverted, servoMin, servoMax);
}

void motorForwardPWM(int pwm) {
    digitalWrite(INA, LOW);
    digitalWrite(INB, HIGH);
    analogWrite(PWM, constrain(pwm, 0, 255));
}

void motorReversePWM(int pwm) {
    digitalWrite(INA, HIGH);
    digitalWrite(INB, LOW);
    analogWrite(PWM, constrain(pwm, 0, 255));
}

void motorStop() {
    digitalWrite(INA, LOW);
    digitalWrite(INB, LOW);
    analogWrite(PWM, 0);
}

bool readTOFPacket(HardwareSerial &port, uint16_t &front, uint16_t &left, uint16_t &right) {
    static uint8_t state = 0;
    static uint8_t buffer[6];
    static uint8_t index = 0;

    while (port.available()) {
        uint8_t c = port.read();

        switch (state) {
            case 0:
                if (c == 0xAA) {
                    index = 0;
                    state = 1;
                }
                break;

            case 1:
                buffer[index++] = c;

                if (index >= 6) {
                    uint16_t newFront = (uint16_t)buffer[0] | ((uint16_t)buffer[1] << 8);
                    uint16_t newLeft  = (uint16_t)buffer[2] | ((uint16_t)buffer[3] << 8);
                    uint16_t newRight = (uint16_t)buffer[4] | ((uint16_t)buffer[5] << 8);

                    if (newFront <= TOF_MAX_VALID_MM) front = newFront;
                    if (newLeft  <= TOF_MAX_VALID_MM) left = newLeft;
                    if (newRight <= TOF_MAX_VALID_MM) right = newRight;

                    Serial.println(newLeft);

                    state = 0;
                    return true;
                }
                break;
        }
    }

    return false;
}

bool readOpenMVPacket(HardwareSerial &port, OpenMVBlob &blob) {
    static uint8_t state = 0;
    static uint8_t buffer[5];
    static uint8_t index = 0;

    while (port.available()) {
        uint8_t c = port.read();

        switch (state) {
            case 0:
                if (c == 0xAA) {
                    index = 0;
                    state = 1;
                }
                break;

            case 1:
                buffer[index++] = c;

                if (index >= 5) {
                    state = 2;
                }
                break;

            case 2:
                if (c == 0x55) {
                    blob.colorId = buffer[0];
                    blob.x = (uint16_t)buffer[1] | ((uint16_t)buffer[2] << 8);
                    blob.y = (uint16_t)buffer[3] | ((uint16_t)buffer[4] << 8);
                    blob.valid = true;

                    state = 0;
                    return true;
                } else {
                    state = 0;
                    index = 0;

                    if (c == 0xAA) {
                        state = 1;
                    }
                }
                break;
        }
    }

    return false;
}

float getBlobAngleDeg(const OpenMVBlob &blob) {
    int dx = (int)blob.x - CAM_CENTER_X;

    float angle = ((float)dx * CAM_HALF_FOV_DEG) / (float)CAM_CENTER_X;

    if (CAM_INVERT_X) {
        angle = -angle;
    }

    return constrain(angle, -CAM_HALF_FOV_DEG, CAM_HALF_FOV_DEG);
}

bool hasFreshBlob() {
    return camBlob.valid && lastCamPacket <= CAM_TIMEOUT_MS;
}

// NO CAMBIÉ ESTA LÓGICA DE EVASIÓN
int getVisionTargetIMU() {
    if (!hasFreshBlob()) {
        return setPointIMU;
    }

    float blobAngle = getBlobAngleDeg(camBlob);
    float correction = 0.0f;

    if (camBlob.colorId == COLOR_GREEN) {
        if (blobAngle > -VISION_DEAD_ZONE_DEG) {
            correction = blobAngle + PASS_OFFSET_DEG;
        }
    }
    else if (camBlob.colorId == COLOR_RED) {
        if (blobAngle < VISION_DEAD_ZONE_DEG) {
            correction = blobAngle - PASS_OFFSET_DEG;
        }
    }

    correction = constrain(correction * CORR_KP, -MAX_VISION_CORRECTION_DEG, MAX_VISION_CORRECTION_DEG);

    return wrap180(setPointIMU + (int)correction);
}
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

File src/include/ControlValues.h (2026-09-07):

#pragma once


//Constants 
#define MAX_VALID_DISTANCE 3000

// Print the complete 8x8 distance matrix from exactly one ToF sensor.
// Change FRONT to LEFT or RIGHT to inspect a different sensor.
#define DEBUG_PRINT_TOFS
#define DEBUG_PRINT_TOF_SIDE TOF4Walls::FRONT


//First lap open round

struct MotionTaskConfig {
    // Same units and field order as Move::setTask.
    float distanceCm;
    float maxSpeedCmS;
    float accelerationCmS2;
    float decelerationCmS2;
    float initialSpeedCmS;
    float finalSpeedCmS;
};

struct SpeedControlConfig {
    // ki is retained for a future integral controller; it is not applied yet.
    float targetSpeedCmS;
    float kp;
    float ki;
};

#define FIRST_GO_STRAIGHT_DISTANCE 95
#define FIRST_GO_STRAIGHT_SPEED 50
#define FIRST_GO_STRAIGHT_ACCEL_DECCEL 30


constexpr MotionTaskConfig OPEN_INITIAL_STRAIGHT_PROFILE = {
    95.0f, 50.0f, 30.0f, 30.0f, 0.0f, 0.0f
};

constexpr MotionTaskConfig OPEN_FOLLOW_WALL_PROFILE = {
    130.0f, 90.0f, 30.0f, 30.0f, 0.0f, 0.0f
};

constexpr MotionTaskConfig OPEN_ENDING_PROFILE = {
    40.0f, 30.0f, 60.0f, 60.0f, 0.0f, 0.0f
};

constexpr SpeedControlConfig OPEN_CRUISE_SPEED_CONTROL = {
    70.0f, 1.0f, 0.1f
};

#define EDGING_PWM -60
#define EDGING_TARGET_DISTANCE 300

#define INITIAL_REVERSE_TIME 1000
#define INITIAL_REVERSE_PWM 70

// follow until edge

#define CRUISE_MIN_DISTANCE_MM 600
#define TURN_MIN_DISTANCE_MM 300
#define TURN_MAX_DISTANCE_MM 700
#define INNER_WALL_MIN_DISTANCE_TO_TURN_MM 3000
#define INNER_WALL_MAX_DISTANCE_TO_CRUISE_MM 3000
#define FOLLOW_WALL_RECOVERY_PWM 100


// Open Turn controls

#define OPEN_TURN_ERROR_THRESHOLD_DEG 5
#define OPEN_TURN_PWM -150
#define OPEN_TURN_STEERING_GAIN 2.0f


// Tangential evasion controls. All distance values in this block are OpenMV pixels.
#define TAN_EVASION_SECURITY_RADIUS_PX 120
#define TAN_EVASION_ACTIVATION_DISTANCE_PX 170
#define TAN_EVASION_FULL_EVASION_DISTANCE_PX 150
#define TAN_EVASION_ORIENTATION_GAIN 1.5f // Gain for orientation error in tangent evasion
#define TAN_EVASION_EVASION_GAIN 2.0f // Gain for evasion
#define TAN_EVASION_KP 2.0f // Proportional gain for PD
#define TAN_EVASION_KD 0.02f // Derivative gain for PD
#define TAN_EVASION_DERIVATIVE_FILTER 0.20f // Derivative filter

// Obstacle Controls
#define OBSTACLES_PWM_DRIVE -80 // Standar Drive PWM
#define OBSTACLES_RECOVERY_TIME_MS 350 // Recovery time when to close to obstacle
#define SIDE_WALLS_ACTIVATION_DISTANCE_MM 100 // Distance to activate tangent evasion maneuver
#define NO_OBSTACLE_IMU_GAIN 3.0f
#define OBSTACLE_CLOSE_RECOVERY_DISTANCE_PX 80 // Image-space distance that starts recovery

// SIDE WALLS CONTROLS
#define SIDE_WALLS_ACTIVATION_DISTANCE_MM 100 // Distance to activate tangent evasion
#define SIDE_WALLS_STEERING_ANGLE_DEG 30 // Steering angle to avoid side walls


// BLUE LINE CONTROLS

#define BLUE_LINE_STABLE_TIME_MS 100 // Minimum time that the blue line must be detected to trigger a turn
#define BLUE_LINE_REARM_DISTANCE_MM 1500.0f // MM that the robot have to travel before trigger other turn


// Vision constants

#define VISION_WIDTH 320
#define VISION_HEIGHT 240

// final lap

#define PARKING_DISTANCE_MM 1500

#define CORNER_DETECTION_DISTANCE_MM 500

// a;adir histeresis a la recuperaicon  de la rodna de obstaculos, 
// mas estados en obstaculos
// corregir que no se inicie IMU
// mas estados para la recuperacion en abierta
// deteccion correcta de aldos en abierta
// deteccion de giro en obstaculos
// mas casos de vueltas en obstaculos para que no choque sie sta muy cerca de la pared a la que gira
// que siga la pared si el obstaculo lo obliga a girar hacia esa pared
// Probar N6
// checar que tan viable es hace homografia  

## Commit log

2026-04-20 added library to get yaw from bno085 TODO: integrate yaw to get absolut rotated degrees
2026-04-20 created library to manage mobility, added fucntion to drive motor by a given pwm TODO: use motor encoderto improve mobility by drive by give ms/s and add methods for brake
2026-04-20 created method for driving motor at given m/s, created method for smooth transition between pwm changues, added credits in TOFS4Walls
2026-04-23 Code working multiple issues fixed
    [Arduino-Teensy.ino, TOF4Walls.cpp]
2026-04-27 Cleaned and improved Xiao Code, added DEBUG_LOG, deleted unncesesary Serial.prints
2026-04-27 fixed duplicated DEBUG_LOG added checksum, added defined variable names for each byte to send for better understading
    [Arduino-Xiao.ino, TOF4Walls.cpp]
2026-04-28 fixed variable names consistency, fixed data trasmition for better speed and consistency
    [Arduino-Xiao.ino, TOF4Walls.cpp]
2026-05-01 created library to manage motor and encoder feedback
2026-07-27 ordered source code to use platformio instead of arduino IDE
2026-07-28 fixed variable name and constants in tof4wall library
    [Arduino-Teensy.ino, Arduino-Xiao.ino, obstaculos-Teensy.ino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]
2026-08-07 code to receive sensors data from xiao
2026-08-07 moddified uart protocol and fixed definitions and constants
    [xiao-main.cpp]
2026-08-07 Added led for debbug
2026-08-08 fixed to work rigth with platofmrio
    [xiao-main.cpp]
2026-08-08 Servo steering methods added
2026-08-15 work on obstacles and fixex for open round
    [ControlValues.h]
2026-08-17 reverted to previus working commit and added logic to do laps in both directions
    [xiao-main.cpp]
2026-09-08 Added electronics
    [CAM-PCB.PcbDoc, CAM-PCB.step, CAM-SCH.SchDoc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]
2026-09-08 Updated circuits
    updates to schematic images

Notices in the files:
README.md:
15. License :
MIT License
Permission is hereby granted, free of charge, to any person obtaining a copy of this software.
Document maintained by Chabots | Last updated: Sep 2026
